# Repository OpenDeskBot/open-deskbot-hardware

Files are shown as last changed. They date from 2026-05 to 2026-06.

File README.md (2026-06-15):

# Brufik

[中文](README_zh.md) | English

**Hardware in this repository is under [CERN-OHL-S-2.0](mechanical/LICENSE); software is under [GPL-3.0](firmware/LICENSE).**

**Brufik** is an open-source deskbot on **Seeed XIAO ESP32S3 Sense**. Backend: [open-deskbot-service](https://github.com/OpenDeskBot/open-deskbot-service).

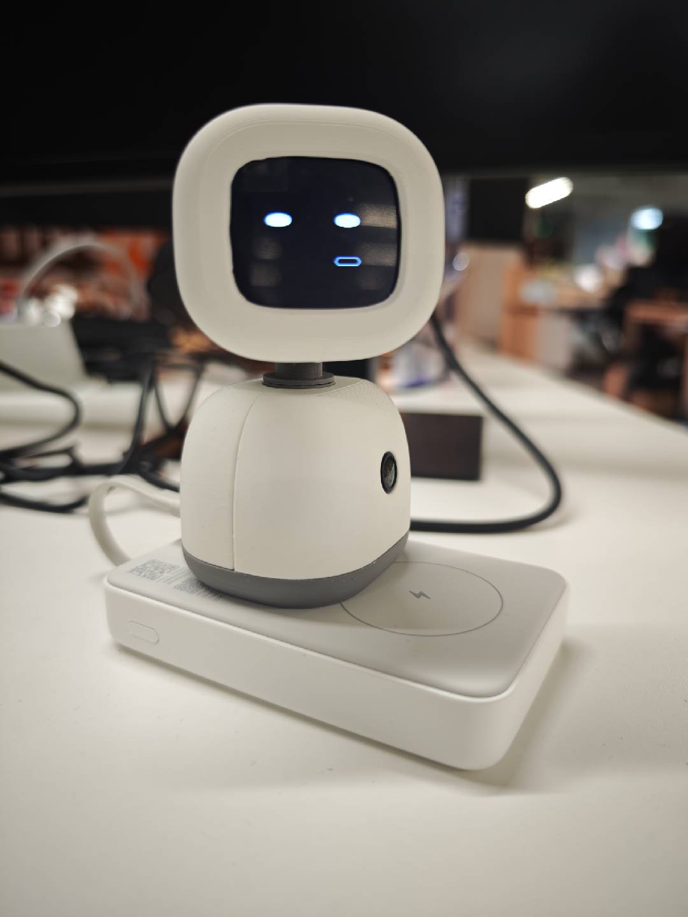
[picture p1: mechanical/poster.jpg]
Brufik deskbot — assembled unit


---

## 1. Out of the box

1. Set your router or phone hotspot to **`deskbot_wifi` / `hello2026`** (defaults in [`firmware/deskbot_config.h`](firmware/deskbot_config.h)).
2. Power on — the device joins that WiFi and talks to your backend.
3. To use another SSID: edit `WIFI_DEFAULT_*` and `DESKBOT_WS_*` before flash, or join AP **`Deskbot_Rom`** → **`http://192.168.4.1/`**.

---

## 2. Developers

Edit [`firmware/deskbot_config.h`](firmware/deskbot_config.h), then:

```bash
./flash_rom.sh all
```

Deploy [open-deskbot-service](https://github.com/OpenDeskBot/open-deskbot-service). Firmware WebSocket: **`/asr_chat`**.

Optional debug: `http://<device-ip>/` for a local camera page.

---

## 3. DIY assembly

| Part | Notes | Search terms |
|---|---|---|
| MCU | Camera module + **onboard mic** on the Sense board (**no extra purchase**) | Seeed XIAO ESP32S3 **Sense** |
| Lens | For **OV2640**; **120°** wide angle; **same-plane** (not off-axis); **25 mm** length | `OV2640 lens 120° same plane 25mm` |
| LCD | 1.83" SPI ST7789 240×284 | Waveshare 1.83 LCD Rev2 |
| Servos | **Large + small**; pan = **2g micro servo**, tilt = larger servo | `2g servo`, `SG90` / `9g servo` |
| Amp | I2S | MAX98357A |
| Speaker | **2011** type | `2011 speaker`, `8Ω 2011` |
| Power | 5V ≥1A for servos | — |
| PCB | This repo includes an extension **PCB** for easier wiring; **hand-wiring without the PCB also works** | — |

### Assembly guide & reference photos

- **Step-by-step manual:** [`mechanical/说明书1.02PDF.pdf`](mechanical/说明书1.02PDF.pdf)
- **All parts laid out:** [`mechanical/parts-overview.png`](mechanical/parts-overview.png)
- **Core assembly done (shell not installed):** [`mechanical/assembly-without-shell.png`](mechanical/assembly-without-shell.png)
- **Side view without shell:** [`mechanical/assembly-side-no-shell.png`](mechanical/assembly-side-no-shell.png)

### Wiring (XIAO pad → device)

> Schematic **IO8 / IO3** = **GPIO numbers**, not silkscreen D8/D3.

| Device | Signals | XIAO pads |
|---|---|---|
| LCD SPI | MOSI/CLK/CS/DC | D10 / D8 / D1 / D2 |
| Servo X (pan) | PWM | **D7** (2g) |
| Servo Y (tilt) | PWM | **D6** (large) |
| MAX98357 | DIN/BCLK/LRC | D0 / D5 / D4 → 2011 speaker |
| Mic | PDM | **Onboard** (ESP32S3 Sense) |

Details: [`firmware/deskbot_config.h`](firmware/deskbot_config.h).

---

## License

| Scope | License | File |
|---|---|---|
| Hardware ([`mechanical/`](mechanical/)) | CERN-OHL-S-2.0 | [`mechanical/LICENSE`](mechanical/LICENSE) |
| Software ([`firmware/`](firmware/) etc.) | GNU GPL v3.0 | [`firmware/LICENSE`](firmware/LICENSE) |

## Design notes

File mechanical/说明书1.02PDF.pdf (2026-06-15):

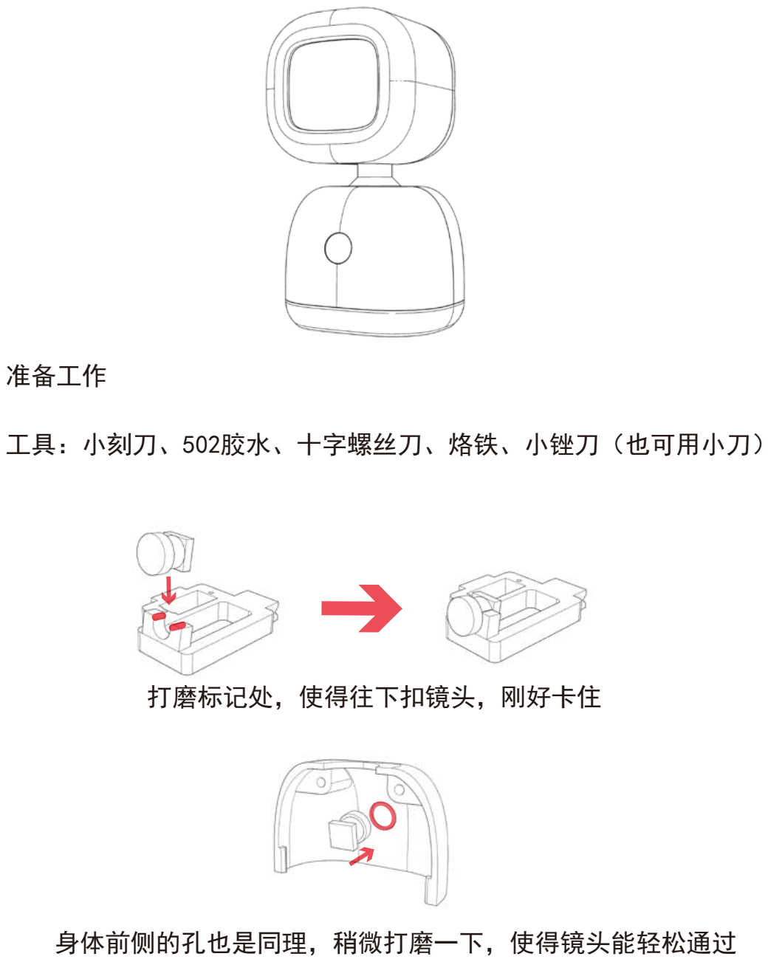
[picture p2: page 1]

## 准备工作

## 工具：小刻刀、502胶水、十字螺丝刀、烙铁、小锉刀（也可用小刀）

## 身体前侧的孔也是同理，稍微打磨一下，使得镜头能轻松通过

## 打磨标记处，使得往下扣镜头，刚好卡住

## 一、转接板焊接

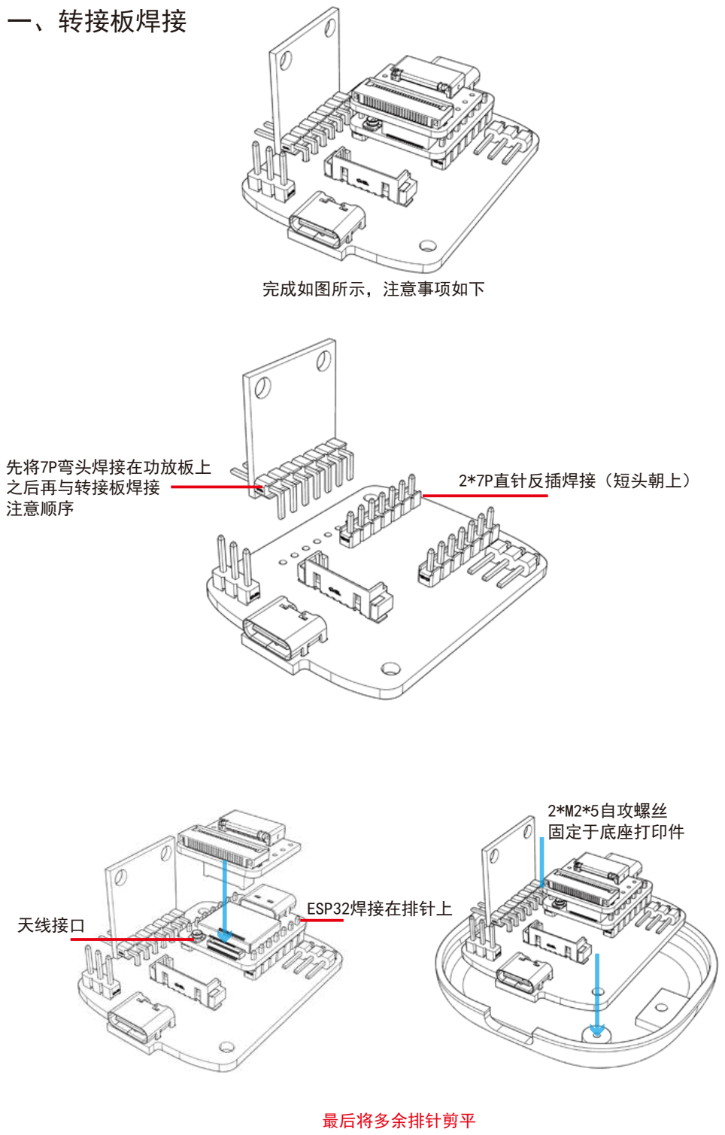
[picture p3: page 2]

先将7P弯头焊接在功放板上
之后再与转接板焊接
注意顺序

2*7P直针反插焊接（短头朝上）

完成如图所示，注意事项如下

天线接口

ESP32焊接在排针上

2*M2*5自攻螺丝
固定于底座打印件

最后将多余排针剪平

## 二、头部组装

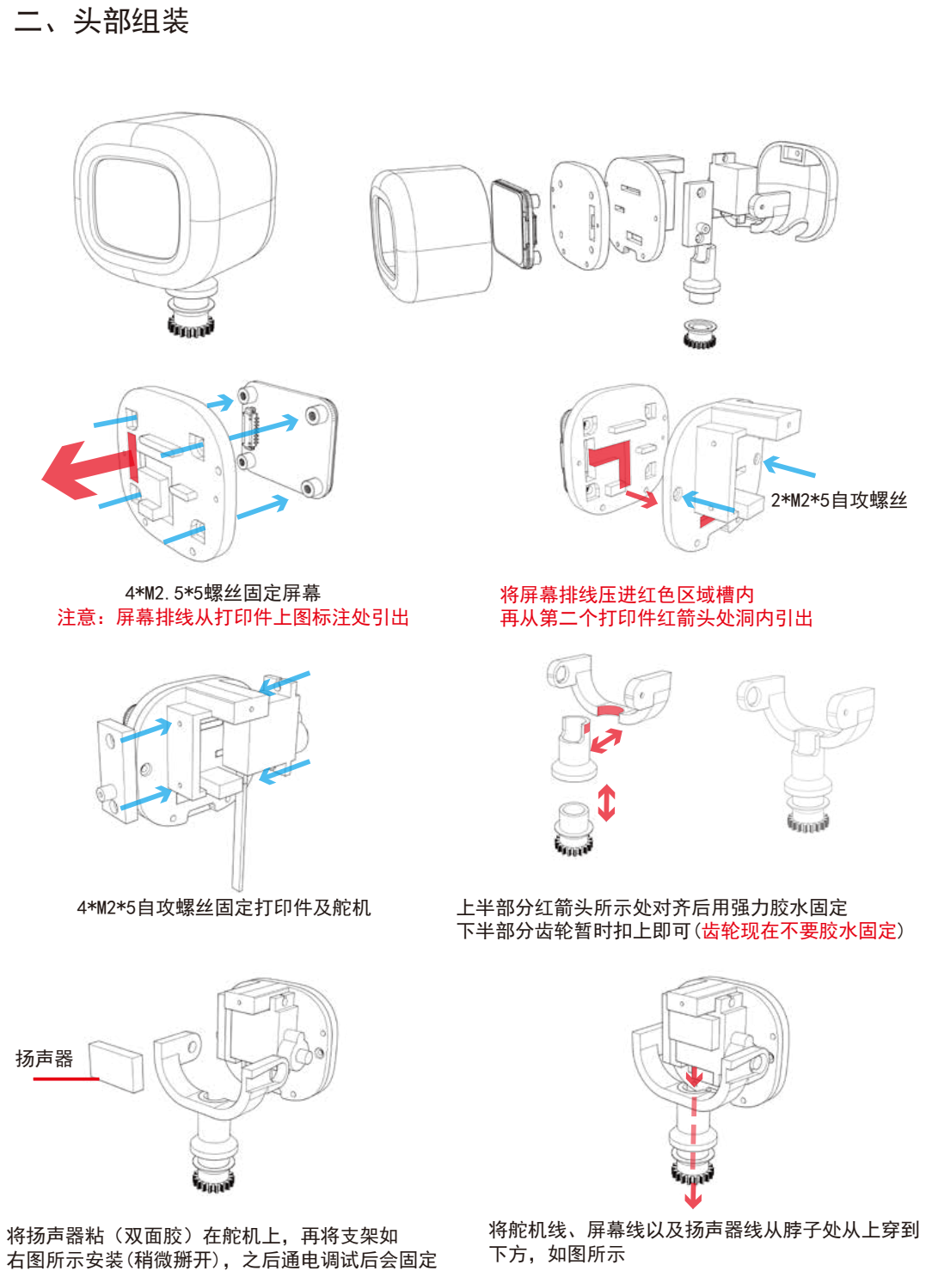
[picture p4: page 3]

扬声器

4*M2.5*5螺丝固定屏幕

4*M2*5自攻螺丝固定打印件及舵机

将舵机线、屏幕线以及扬声器线从脖子处从上穿到
下方，如图所示 将扬声器粘（双面胶）在舵机上，再将支架如 右图所示安装(稍微掰开)，之后通电调试后会固定

上半部分红箭头所示处对齐后用强力胶水固定
下半部分齿轮暂时扣上即可(齿轮现在不要胶水固定)

将屏幕排线压进红色区域槽内
再从第二个打印件红箭头处洞内引出

2*M2*5自攻螺丝

注意：屏幕排线从打印件上图标注处引出

## 三、身体组装

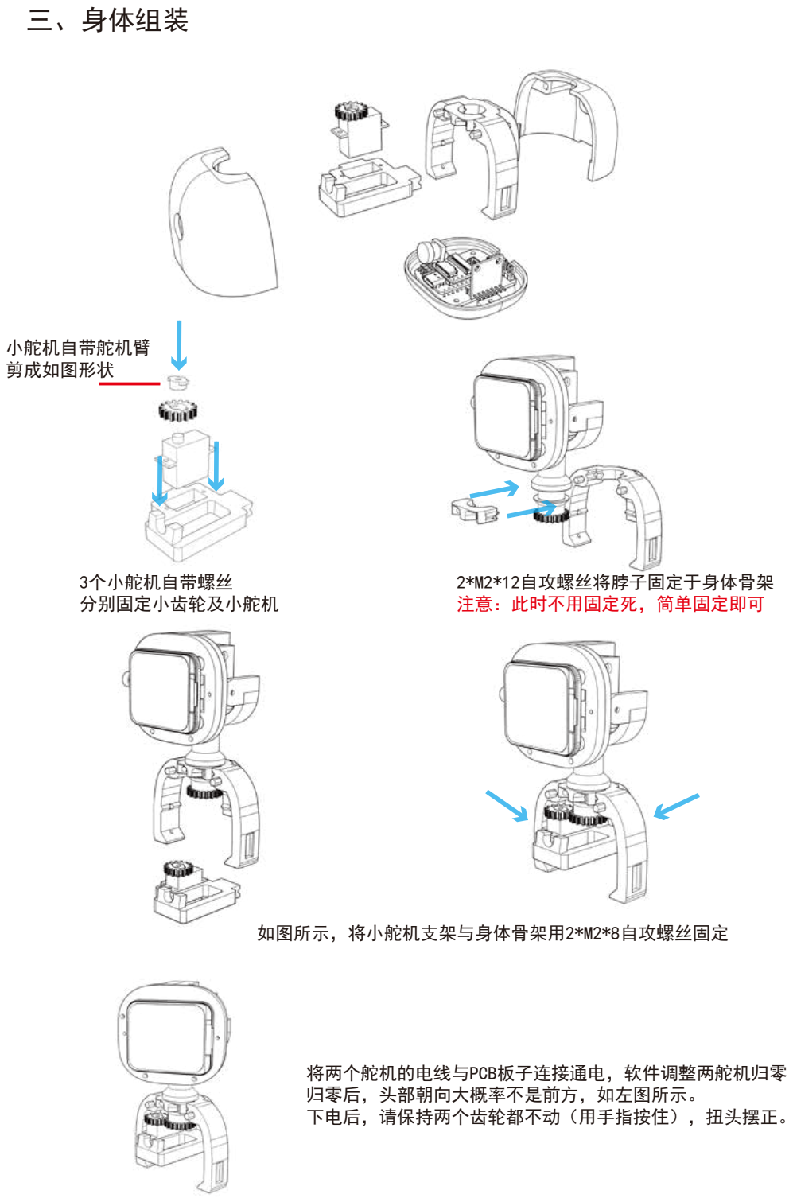
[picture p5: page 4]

小舵机自带舵机臂
剪成如图形状

将两个舵机的电线与PCB板子连接通电，软件调整两舵机归零 归零后，头部朝向大概率不是前方，如左图所示。
下电后，请保持两个齿轮都不动（用手指按住），扭头摆正。

3个小舵机自带螺丝
分别固定小齿轮及小舵机

2*M2*12自攻螺丝将脖子固定于身体骨架
注意：此时不用固定死，简单固定即可

如图所示，将小舵机支架与身体骨架用2*M2*8自攻螺丝固定

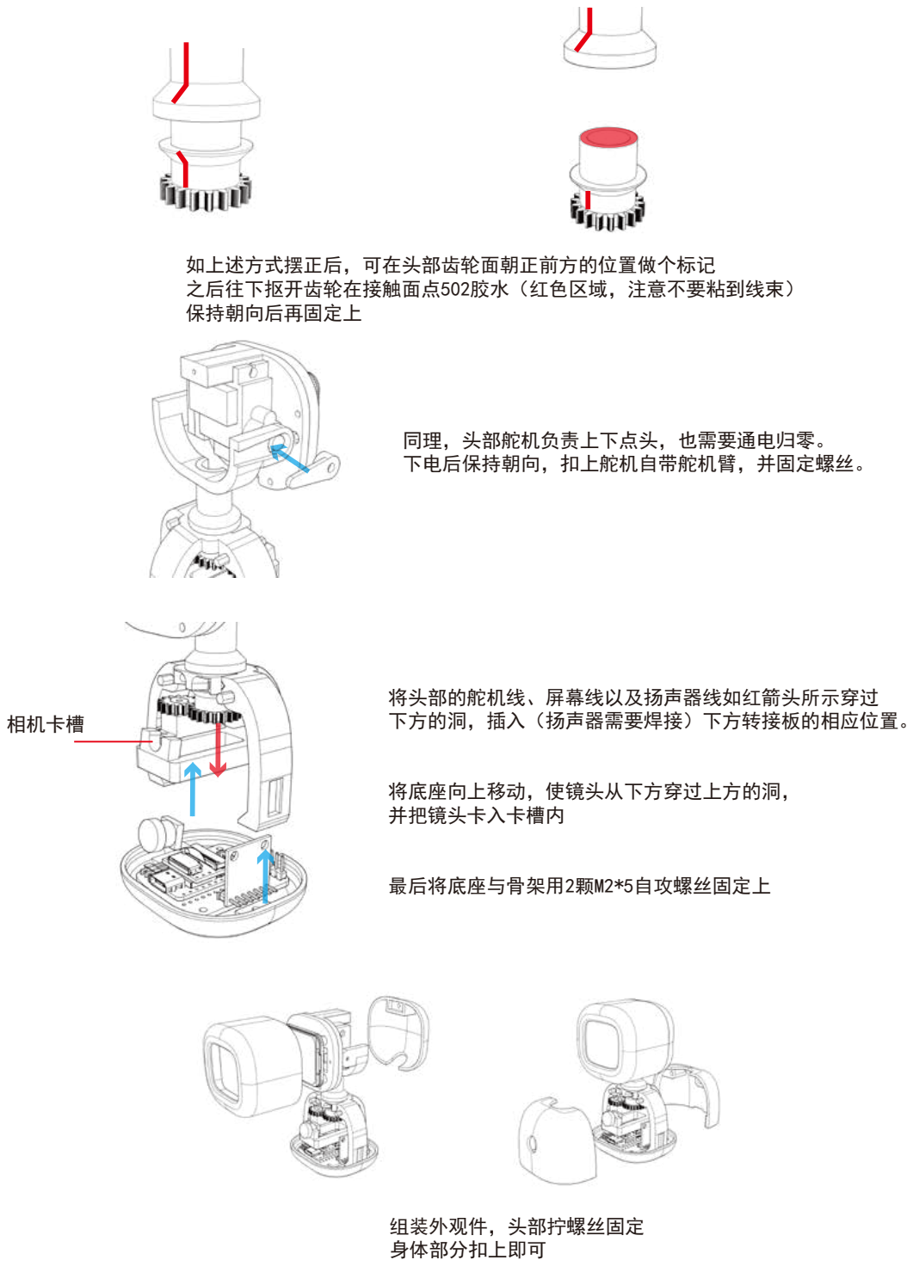
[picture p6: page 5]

如上述方式摆正后，可在头部齿轮面朝正前方的位置做个标记 之后往下抠开齿轮在接触面点502胶水（红色区域，注意不要粘到线束） 保持朝向后再固定上

同理，头部舵机负责上下点头，也需要通电归零。
下电后保持朝向，扣上舵机自带舵机臂，并固定螺丝。

相机卡槽

将头部的舵机线、屏幕线以及扬声器线如红箭头所示穿过
下方的洞，插入（扬声器需要焊接）下方转接板的相应位置。

将底座向上移动，使镜头从下方穿过上方的洞，
并把镜头卡入卡槽内

最后将底座与骨架用2颗M2*5自攻螺丝固定上

组装外观件，头部拧螺丝固定
身体部分扣上即可

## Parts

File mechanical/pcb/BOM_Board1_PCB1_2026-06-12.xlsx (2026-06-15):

No. | Quantity | Comment | Designator | Footprint | Value | Manufacturer Part | Manufacturer | Supplier Part | Supplier
1 | 2 | 5.1kΩ | 1K1,5.1k | R0805 | 5.1kΩ | 0805W8F5101T5E | UNI-ROYAL(厚声) | C27834 | LCSC
2 | 2 | PZ254V-11-07P | H3,H4 | HDR-TH_7P-P2.54-V-M |  | PZ254V-11-07P | XFCN(兴飞) | C492406 | LCSC
3 | 1 | TYPE-C 6P(073) | USB1 | TYPE-C-SMD_TYPE-C-6P-073 |  | TYPE-C 6P(073) | SHOU HAN(首韩) | C668623 | LCSC
4 | 1 | ZX-MX1.25-8PLT | vcc | CONN-SMD_8P-P1.25_ZX-MX1.25-8PLT |  | ZX-MX1.25-8PLT | Megastar(兆星) | C19272385 | LCSC
5 | 1 | PZ254R-11-07P | vin | HDR-TH_7P-P2.54-H-M-W10.4 |  | PZ254R-11-07P | XFCN(兴飞) | C492415 | LCSC
6 | 1 | PZ254R-11-03P | X舵机 | HDR-TH_3P-P2.54-H-M-W10.4 |  | PZ254R-11-03P | XFCN(兴飞) | C492411 | LCSC
7 | 1 | PZ254V-11-03P | Y舵机 | HDR-TH_3P-P2.54-V-M_PZ254V-11-03P |  | PZ254V-11-03P | XFCN(兴飞) | C2937625 | LCSC

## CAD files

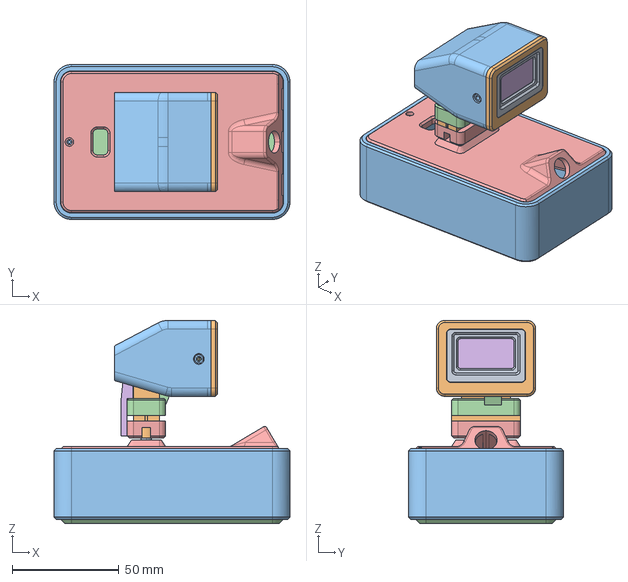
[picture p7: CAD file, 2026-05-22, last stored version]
mechanical/小歪001.stp
110.3 x 72.4 x 95.0 mm
齿轮 x 2
舵机 x 2

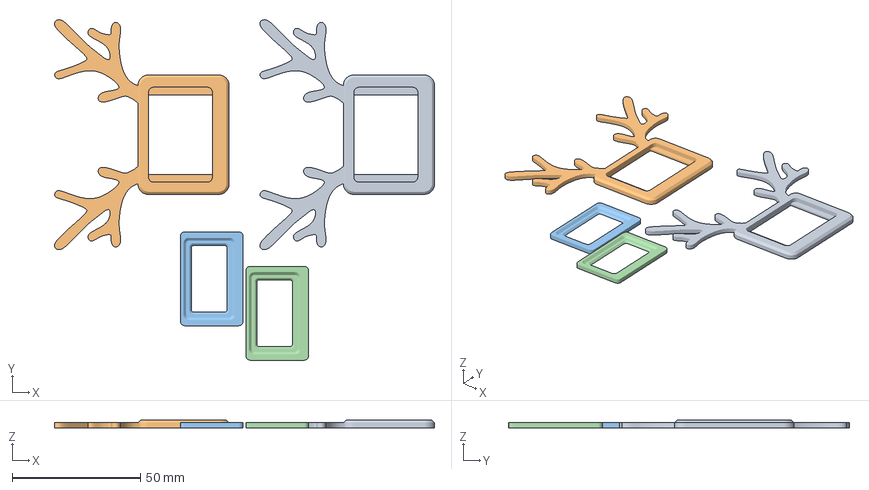
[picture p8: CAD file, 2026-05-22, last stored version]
mechanical/鹿角.3mf
148.1 x 132.7 x 3.00 mm
Document_1 x 2
Document_2 x 2

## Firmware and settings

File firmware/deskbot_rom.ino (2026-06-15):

// Deskbot — XIAO ESP32S3 Sense：摄像头 + asr_chat(pb) + 音频 + LCD + 舵机
#include "esp_camera.h"
#include <WiFi.h>
#include "oled_display.h"
#include "img_converters.h"
#include "camera_ws.h"
#include "deskbot_config.h"
#include "wifi_provision.h"
#include "common.h"
#include "oled.h"
#include "audio_player.h"
#include "audio_capture.h"
#include "asr_chat_client.h"
#include "head.h"
#include "cmd.h"
#include "task_trace.h"

#include "camera_pins.h"

void startCameraServer();

AsrChatClient asrChatClient;

unsigned long loop_start_time = 0;

static bool setup_camera() {
  camera_config_t config;
  config.ledc_channel = LEDC_CHANNEL_0;
  config.ledc_timer = LEDC_TIMER_0;
  config.pin_d0 = Y2_GPIO_NUM;
  config.pin_d1 = Y3_GPIO_NUM;
  config.pin_d2 = Y4_GPIO_NUM;
  config.pin_d3 = Y5_GPIO_NUM;
  config.pin_d4 = Y6_GPIO_NUM;
  config.pin_d5 = Y7_GPIO_NUM;
  config.pin_d6 = Y8_GPIO_NUM;
  config.pin_d7 = Y9_GPIO_NUM;
  config.pin_xclk = XCLK_GPIO_NUM;
  config.pin_pclk = PCLK_GPIO_NUM;
  config.pin_vsync = VSYNC_GPIO_NUM;
  config.pin_href = HREF_GPIO_NUM;
  config.pin_sscb_sda = SIOD_GPIO_NUM;
  config.pin_sscb_scl = SIOC_GPIO_NUM;
  config.pin_pwdn = PWDN_GPIO_NUM;
  config.pin_reset = RESET_GPIO_NUM;
  config.xclk_freq_hz = 20000000;
  config.frame_size = FRAMESIZE_UXGA;
  config.pixel_format = PIXFORMAT_JPEG;
  config.grab_mode = CAMERA_GRAB_WHEN_EMPTY;
  config.fb_location = CAMERA_FB_IN_PSRAM;
  config.jpeg_quality = 12;
  config.fb_count = 1;

  if (psramFound()) {
    config.jpeg_quality = 10;
    config.fb_count = 2;
    config.grab_mode = CAMERA_GRAB_LATEST;
  } else {
    config.frame_size = FRAMESIZE_SVGA;
    config.fb_location = CAMERA_FB_IN_DRAM;
  }

  esp_err_t err = esp_camera_init(&config);
  if (err != ESP_OK) {
    log_error("Camera init failed 0x%x", err);
    return false;
  }

  sensor_t *s = esp_camera_sensor_get();
  if (s->id.PID == OV3660_PID) {
    s->set_vflip(s, 1);
    s->set_brightness(s, 1);
    s->set_saturation(s, -2);
  }
  if (config.pixel_format == PIXFORMAT_JPEG) {
    s->set_framesize(s, FRAMESIZE_QVGA);
  }
  return true;
}

void websocket_loop() {
  asrChatClient.loop();
}

void setup() {
  Serial.begin(115200);
  Serial.flush();
  /* USB CDC 在 ESP32-S3 上 !Serial 永远为 false，用固定 delay 等待监视器连接。
   * 3s 足够 Linux/macOS 完成 USB CDC 枚举并让 flash_rom.sh 启动监视器。
   * 独立运行（无 USB）时同样只多等 3s，不影响正常功能。 */
  delay(3000);
  log_set_level(LOG_LEVEL_INFO);
  log_info("Initializing Deskbot...");

  setup_oled();
  setup_FFat();
  setup_led();

  /* 归中用 LEDC timer2（在 camera 占 timer0 之前）；attach 在 camera 之后。 */
  setup_head();

  static bool s_camera_ok = false;
  s_camera_ok = setup_camera();
  head_servo_boot_attach();
  log_set_level(LOG_LEVEL_WARN);
  deskbot_lcd_backlight_on();
  if (!s_camera_ok) {
    log_warn("[BOOT] Camera absent or failed — continuing without camera");
    oled_boot_show("无摄像头", "继续启动...");
  }
  if (!wifi_provision_connect()) {
    log_error("WiFi connect failed");
    oled_boot_show("WiFi 连接失败", "请重启或配网");
    return;
  }

  setup_audio();
  mic_capture_setup();
  audio_play_task_setup();
  display_task_setup();

  log_info("[BOOT] firmware=%s %s %s", VERSION, __DATE__, __TIME__);
  log_info("[BOOT] device_id=%s ws=%s:%u api_key=%s", get_device_id(), DESKBOT_WS_HOST,
           (unsigned)DESKBOT_WS_PORT, deskbot_api_key_configured() ? "set" : "MISSING");
  log_info("PSRAM size=%u free=%u", (unsigned)ESP.getPsramSize(), (unsigned)ESP.getFreePsram());

  if (s_camera_ok) {
    camera_ws_init();
    startCameraServer();
  } else {
    log_warn("[BOOT] Skipping camera server / vision tasks (no camera)");
  }

  oled_boot_show_ready();
  log_info("%s is Ready. http://%s", PRODUCT_NAME, WiFi.localIP().toString().c_str());
  loop_start_time = millis();
  start_chat = true;
}

void loop() {
  handle_cmd();
  websocket_loop();
  log_task_tick();

  if (start_chat) {
    start_chat = false;
    loop_start_time = millis();
    if (CHAT_LOOP_MAX_MS > 0) {
      log_info("[CHAT] enter asr_chat loop (max %lu ms)", (unsigned long)CHAT_LOOP_MAX_MS);
    } else {
      log_info("[CHAT] enter asr_chat loop (no auto exit)");
    }
    for (;;) {
      /* 长会话内也要读串口，否则 factory 等命令无响应 */
      handle_cmd();
      log_task_tick();
      if (CHAT_LOOP_MAX_MS > 0 && (millis() - loop_start_time >= (unsigned long)CHAT_LOOP_MAX_MS)) {
        break;
      }
      if (!asrChatClient.runVoiceRound(RECORD_TIME)) {
        log_error("[CHAT] asr_chat round failed, reconnect retry in 2s");
        blink_led(COLOR_RED, 3);
        delay(2000);
        continue;
      }
      websocket_loop();
      delay(500);
    }
    log_info("[CHAT] leave chat loop");
  }

  delay(10);
}

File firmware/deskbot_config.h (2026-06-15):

#pragma once

#include <stddef.h>
#include <driver/gpio.h>

/* ========== 烧录前可改：网络 ==========
 * 默认连 deskbot_wifi；也可改成你的路由器 SSID/密码。
 * 若 SSID 留空 → 热点 Deskbot_Rom，http://192.168.4.1/ 配网；NVS 已存凭证优先。
 * WS host 留空 → 禁用 WebSocket 上行。
 */
#define WIFI_DEFAULT_SSID "deskbot_wifi"
#define WIFI_DEFAULT_PASSWORD "hello2026"

#define DESKBOT_WS_HOST "39.107.38.241"
#define DESKBOT_WS_PORT 9000

/* 服务端 WebSocket 鉴权 Key（odk_... 或 odk_free_...）。留空则无法连接 /asr_chat。 */
#define DESKBOT_API_KEY "odk_free_k60xNgMyI6A-09nP1Tc6gQ67tnHPcMgF"

#define ASR_CHAT_HOST DESKBOT_WS_HOST
#define ASR_CHAT_PORT DESKBOT_WS_PORT

static inline bool deskbot_ws_configured(void) {
  return DESKBOT_WS_HOST[0] != '\0';
}

static inline bool deskbot_api_key_configured(void) {
  return DESKBOT_API_KEY[0] != '\0';
}

/* ========== 硬件接线（Seeed XIAO ESP32S3 Sense）==========
 * 焊盘: D0=1 D1=2 D2=3 D3=4 D4=5 D5=6 D6=43 D7=44 D8=7 D9=8 D10=9
 * 图纸 IO8/IO3 = GPIO 编号，非丝印 D8/D3。
 * LCD：微雪 1.83" ST7789P 240×284，RST/BL 接 3.3V（不经 MCU GPIO）
 */

#define DESKBOT_LCD_MOSI 9
#define DESKBOT_LCD_SCK  7
#define DESKBOT_LCD_CS   2
#define DESKBOT_LCD_DC   3

#define DESKBOT_LCD_WIDTH 240
#ifndef DESKBOT_LCD_HEIGHT
#define DESKBOT_LCD_HEIGHT 284
#endif
#ifndef DESKBOT_LCD_ROW_OFFSET
#define DESKBOT_LCD_ROW_OFFSET 36
#endif
#ifndef DESKBOT_LCD_COL_OFFSET
#define DESKBOT_LCD_COL_OFFSET 0
#endif

#ifndef DESKBOT_LCD_TOP_SAFE_PX
#define DESKBOT_LCD_TOP_SAFE_PX 4
#endif

#define DESKBOT_PB_COORD_W DESKBOT_LCD_HEIGHT
#define DESKBOT_PB_COORD_H 240
#ifndef DESKBOT_LCD_CANVAS_X0
#define DESKBOT_LCD_CANVAS_X0 ((DESKBOT_LCD_HEIGHT - DESKBOT_PB_COORD_W) / 2)
#endif
#ifndef DESKBOT_LCD_ROT3_XSTART_ADJ
#define DESKBOT_LCD_ROT3_XSTART_ADJ (-18)
#endif

#define DESKBOT_DRAW_W DESKBOT_PB_COORD_W
#define DESKBOT_DRAW_H DESKBOT_PB_COORD_H

/* 舵机 PWM：丝印 D6=GPIO43，D7=GPIO44（芯片默认 UART0，Bootloader 日志易致误动作）
 * 左右(X) → D7/44 小舵机；上下(Y) → D6/43 大舵机
 * 保护：custom bootloader + servo_early_init constructor + setup claim LOW */
#ifndef DESKBOT_ROM_X_PIN
#define DESKBOT_ROM_X_PIN 44
#endif
#ifndef DESKBOT_ROM_Y_PIN
#define DESKBOT_ROM_Y_PIN 43
#endif

#ifndef DESKBOT_AUDIO_PLAY_VOLUME
#define DESKBOT_AUDIO_PLAY_VOLUME 0.85f
#endif

#define DESKBOT_ROM_MAX98357_DIN  GPIO_NUM_1
#define DESKBOT_ROM_MAX98357_BCLK GPIO_NUM_6
#define DESKBOT_ROM_MAX98357_LRC  GPIO_NUM_5
#define DESKBOT_ROM_MAX98357_SD   GPIO_NUM_NC
#define DESKBOT_ROM_MAX98357_GAIN GPIO_NUM_NC

#define DESKBOT_PDM_MIC_CLK  GPIO_NUM_42
#define DESKBOT_PDM_MIC_DATA GPIO_NUM_41
#define DESKBOT_PDM_VOICE_MARGIN             220
#define DESKBOT_PDM_VOICE_HANGOVER_MARGIN    180
#define DESKBOT_PDM_VOICE_TRIGGER_RATIO_NUM    105
#define DESKBOT_PDM_VOICE_TRIGGER_RATIO_DEN  100

static inline size_t deskbot_pdm_voice_trigger_thr(size_t ema) {
  const size_t t_delta = ema + (size_t)DESKBOT_PDM_VOICE_MARGIN;
  const size_t t_ratio =
      (ema * (size_t)DESKBOT_PDM_VOICE_TRIGGER_RATIO_NUM) / (size_t)DESKBOT_PDM_VOICE_TRIGGER_RATIO_DEN;
  return (t_delta < t_ratio) ? t_delta : t_ratio;
}

static inline size_t deskbot_pdm_voice_hangover_thr(size_t ema) {
  return ema + (size_t)DESKBOT_PDM_VOICE_HANGOVER_MARGIN;
}
#define DESKBOT_PDM_EMA_QUIET_RATIO_NUM      102
#define DESKBOT_PDM_EMA_QUIET_RATIO_DEN      100
#define DESKBOT_PDM_VOICE_TRIGGER_FRAMES     1
#define DESKBOT_PDM_VOICE_THRESHOLD_MAX      24000
#define DESKBOT_PDM_PRE_VOICE_FRAMES         50
#define DESKBOT_PDM_SILENCE_END_MS           2000

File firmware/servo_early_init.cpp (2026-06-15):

// 在 setup() 之前把舵机信号线从 UART0 切到 GPIO 输出 LOW。
#include "deskbot_config.h"
#include <driver/gpio.h>
#include <soc/gpio_periph.h>
#include <soc/io_mux_reg.h>

static void deskbot_servo_pin_claim_low(gpio_num_t pin) {
  PIN_FUNC_SELECT(GPIO_PIN_MUX_REG[pin], PIN_FUNC_GPIO);
  gpio_config_t cfg = {};
  cfg.pin_bit_mask = 1ULL << pin;
  cfg.mode = GPIO_MODE_OUTPUT;
  cfg.pull_up_en = GPIO_PULLUP_DISABLE;
  cfg.pull_down_en = GPIO_PULLDOWN_ENABLE;
  cfg.intr_type = GPIO_INTR_DISABLE;
  gpio_config(&cfg);
  gpio_set_level(pin, 0);
}

__attribute__((constructor(101))) static void deskbot_servo_pins_early_init(void) {
  deskbot_servo_pin_claim_low((gpio_num_t)DESKBOT_ROM_X_PIN);
  deskbot_servo_pin_claim_low((gpio_num_t)DESKBOT_ROM_Y_PIN);
}

void deskbot_servo_pins_claim_low(void) {
  deskbot_servo_pin_claim_low((gpio_num_t)DESKBOT_ROM_X_PIN);
  deskbot_servo_pin_claim_low((gpio_num_t)DESKBOT_ROM_Y_PIN);
}

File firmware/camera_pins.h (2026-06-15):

#pragma once

/* Seeed XIAO ESP32S3 Sense 摄像头引脚（esp32-camera 示例同源） */

#define PWDN_GPIO_NUM -1
#define RESET_GPIO_NUM -1
#define XCLK_GPIO_NUM 10
#define SIOD_GPIO_NUM 40
#define SIOC_GPIO_NUM 39

#define Y9_GPIO_NUM 48
#define Y8_GPIO_NUM 11
#define Y7_GPIO_NUM 12
#define Y6_GPIO_NUM 14
#define Y5_GPIO_NUM 16
#define Y4_GPIO_NUM 18
#define Y3_GPIO_NUM 17
#define Y2_GPIO_NUM 15
#define VSYNC_GPIO_NUM 38
#define HREF_GPIO_NUM 47
#define PCLK_GPIO_NUM 13

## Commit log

2026-06-15 Restructure as Brufik: unified firmware, bootloader, and mechanical assets.
    Consolidate deskbot-rom and deskbot-camera into a single root-level firmware tree with custom bootloader support and updated Brufik mechanical documentation for public release.
    [BOM_Board1_PCB1_2026-06-12.xlsx, PickAndPlace_PCB1_2026_06_12.xlsx, deskbot_rom_8MB.csv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]
2026-06-15 Add product photo to README for a clearer first impression.
    Show the assembled Brufik unit at the top of both English and Chinese README files.
